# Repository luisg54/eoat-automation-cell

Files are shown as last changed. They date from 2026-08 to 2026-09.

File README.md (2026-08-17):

# EOAT Automation Cell

A small-scale automated pick station combining a custom-designed end-of-arm tool (EOAT), a
motion system, and PLC-based control logic — built to apply industry locating and fixturing
principles (NAAMS-inspired) and to integrate PLC sequencing with a separate motion
controller, mirroring how PLC-to-robot I/O handshakes work in real automation cells.

## Status

Concept and CAD phase. Started June 2026, primary solo project for Fall 2026.

Nothing is built yet. Some hardware is in hand — see [`electrical/bom.md`](electrical/bom.md).

## Repo structure

| Path | Contents |
|---|---|
| `cad/` | CAD models and renders for the gripper/EOAT and gantry |
| `firmware/` | Arduino motion control code |
| `plc/` | Allen-Bradley Micro820 ladder logic (CCW project files) |
| `electrical/` | Wiring diagrams and bill of materials |
| `docs/` | Requirements, test plan, build log, photos, demo videos |

Planning documents: [`docs/requirements.md`](docs/requirements.md) ·
[`docs/test-plan.md`](docs/test-plan.md) ·
[`docs/cycle-animation.html`](docs/cycle-animation.html) ·
[`docs/concept-sketches.html`](docs/concept-sketches.html) ·
[`HANDOFF.md`](HANDOFF.md)

## Project goals

- Design a gripper/locating fixture around a deliberate real-world constraint — geometry
  clearance and tolerance stack-up
- Validate the CAD design against a built, 3D-printed prototype
- Build a small motion system for pick sequences
- Integrate a Micro820 PLC for sensor logic, safety interlocks, and sequencing, handshaking
  with the motion controller

## Success criteria

The single statement that decides whether this project worked:

> The system shall autonomously detect, pick, transfer, and place a part for 50 consecutive
> cycles with at least 98% successful completion, documented fault handling, and measured
> positional repeatability.

Full requirement set in [`docs/requirements.md`](docs/requirements.md).

## Phases

Each phase is independently demonstrable. No phase starts before the previous one has
measured results.

| Phase | Goal | Demonstrable output | Status |
|---|---|---|---|
| 1 — Mechanical proof | One pick object, defined pickup and destination poses, one gripper/locating tool, one gantry X axis + short EOAT Z stroke, repeatable hard stops | Manual cycle with basic repeatability data | Not started |
| 2 — Motion and sensing | Motion controller, home switch, part-present sensor, end-position confirmation | Repeatable automatic pick-and-place cycle | Not started |
| 3 — PLC supervisory control | PLC owns cycle start, permissives, state sequence, sensor validation, faults, reset, and the handshake; motion controller owns low-level movement | Fault injected, detected, reported, recovered | Not started |
| 4 — Validation | Measure repeatability, pick rate, cycle time, fault recovery, tolerance sensitivity, payload, gripper retention, sensor robustness | Completed test report | Not started |

## Scope

**In scope:** one pick object (**608ZZ bearing**), one pickup pose and one destination pose, one gripper or
locating tool, one gantry (X) axis plus a short EOAT Z servo (≥ 15 mm) to clear locators, repeatable hard stops, home/part-present/end-position
sensing, PLC supervisory control over a motion controller, and measured validation.

**Explicitly out of scope:** multiple part types, a part feeder, vision, and any industrial
communication architecture beyond a simple PLC-to-motion handshake.

The known failure mode for a project like this is fragmenting it into five — a custom EOAT
plus a custom gantry plus motion control plus a PLC system plus a comms architecture — and
finishing none. The smallest complete system comes first, then it extends.

## Results

Empty until measured. This section gets filled from `docs/test-plan.md`, not from
expectations.

| Metric | Target | Measured |
|---|---|---|
| Positional repeatability | TBD | |
| Successful pick rate | ≥ 98% over 50 cycles | |
| Cycle time | TBD | |
| Payload | TBD | |

## License

See [`LICENSE`](LICENSE).

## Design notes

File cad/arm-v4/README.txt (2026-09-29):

REVISION D — DEVELOPMENT, owned-servo update 2026-09-28 (first D build 2026-09-12)

User-authored revision C fillets/chamfers were inspected and preserved before work.
The original cad/arm-v3 directory has not been regenerated or overwritten.

Owned servo geometry (authoritative, measured natively into owned-servo-measurements.json):
parts/MG996R_servo.SLDPRT   shoulder and elbow (two owned MG996Rs)
parts/SERVO_SG90.SLDPRT     yaw (one of four owned SG90s; three are unused spares)
Neither file contains a horn, so the joints drive straight off the splines.
The nominal HW-003/HW-004/HW-005/HW-006 envelopes, ARM-112 cap and their fasteners are
suppressed in every configuration of the D assembly (kept, not deleted).

Structural parts:
ARM-201 Upper link: owned MG996R elbow window/M3 ears; PCD18 hub bolt circle.
ARM-202 Yaw platform: derived from user C ARM-002; upright removed.
ARM-203 Shoulder upright: owned MG996R window and M3 ear holes; four-bolt foot.
ARM-204 Straight modular forearm: PCD18 hub bolt circle.
ARM-205 Removable Pololu 3551 gripper fork.
ARM-206 Two spacers preventing inward clamping of the gripper's plastic ears.
ARM-207 Printed MG996R spline hub (x2): press socket on the 25T spline, M3 centre screw.
ARM-003 Yaw collar: press socket on the SG90 spline; floating crossbolt hole.
ARM-004 Yaw cassette: SG90 ear holes on the measured 27.8 mm pitch.
FIT-003 / FIT-004: spline press-fit coupons. Print these, and FIT-001, first.

Scripts for this update: measure_owned_servos.py, owned_servo_design.py,
build_owned_servo_parts.py, update_owned_servo_assembly.py,
suppress_superseded_components.py; verification: check_motion.py,
check_transfer_path.py, save_pose_configurations.py, verify_saved_assembly.py.
One SolidWorks COM script at a time; restart SolidWorks if its working set nears 2 GB.

The supplier STEP and dimension drawing are preserved in source-reference.
HW-202 and HW-203 are purchased gripper reference geometry, not printed parts.
The gripper is a $29.95 candidate; supplier backorders were shown on 2026-09-12.

Use only fabrication-trial/manifest.json and its files for printing. Uncurated STL/STEP
files under parts are development exports, not a printing release. Do not print the parts
folder or fabrication-trial/superseded-2026-09-28.

development-debug/before-owned-servo-geometry-20260928-180253 holds the pre-update D.
development-debug/USER-C_20260912_original_references.SLDASM is a backup of C and
intentionally still references original C paths. It is not revision D.

Still required: servo spline press fits (FIT-003/FIT-004), bearing/dowel fits, calipering
the owned servos, tool access, cable routing, friction, temperature/current and repeated
cycles. More serviceable CAD does not establish production readiness without those tests.

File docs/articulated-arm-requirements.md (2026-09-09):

# Articulated arm prototype — active CAD requirements

On 2026-09-07 Luis explicitly selected an articulated robot arm and authorized identifying additional hardware. The older single-X-slide plus EOAT-Z scheme in `requirements.md` is historical context, superseded for this CAD task.

1. Create base yaw, shoulder pitch, elbow pitch and a working gripper in SolidWorks Design 2026. Use purchased SG90s where suitable. Preserve a provisional 20 g payload target from prior requirements; it remains unverified.
2. Design serviceable joints with explicit radial support, axial retention, fasteners, horn connections, mounting adjustment and cable paths. Incorporate the purchased 608ZZ and 6.35 × 25.4 mm dowel dimensions correctly. Never treat incompatible diameters as a fit.
3. Check first-principles torque, mass, grip, motion and stability. Separate assumptions, source ratings, CAD measurements and physical results.
4. Produce named editable native parts and a native assembly with appropriate joint constraints, plus clearly labeled fabrication exports. Mesh-only models and fixed arrangements without functioning joints do not satisfy this task.
5. Verify solids, saved/reopened files, assembly references, travel, hardware access, working pickup poses and swept interference. Current 60/65 mm link sizing remains a candidate until verified with actual component mass and geometry.
6. Provide materials, printing, assembly, additional hardware and test guidance. Exact fastener stacks must be checked in CAD. No purchasing is authorized by this task.
7. Preserve the previous prototype, work in a separate revision folder and operate conservatively within 16 GB RAM. Close saved task-owned documents and avoid unnecessary detailed geometry.

Native CAD is in development. No physical performance result or print-ready release has been recorded.

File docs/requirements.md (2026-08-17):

# EOAT / Automation Cell — Requirements

**Written:** not yet finalized — draft seeded 2026-08-11
**Last revised:** 2026-08-13

Fill these in with real numbers before opening CAD. Targets marked TBD should be set from
realistic hardware performance, not from ambition. It is better to set a target you can hit
and then tighten it than to miss a number you invented.

## Success criteria

The single statement that decides whether this project worked:

> The system shall autonomously detect, pick, transfer, and place a part for 50 consecutive
> cycles with at least 98% successful completion, documented fault handling, and measured
> positional repeatability.

## Pick object (locked 2026-08-12)

| | |
|---|---|
| **Part** | 608ZZ skate bearing |
| **Why this part** | Rigid, identical, cheap, ferrous (inductive prox), light enough for the SG90, and it has an ID that can take a locating pin — the same class of constraint problem as industrial hole locating |
| **Nominal geometry** | 22 mm OD / 8 mm ID / 7 mm width |
| **Nominal mass** | ~12 g (confirm on a scale before setting final P-04) |
| **Qty to buy** | 5 (spares for drop and offset tests) |

A round bearing has **no clocking datum**. Full 3-2-1 (hole + slot + plane) is out of scope for this object. That is accepted. What this object *is* set up to teach:

- **Hole locating** — pickup nest constrains XY with an ID pin and Z with a rest face
- **Clearance vs constraint** — gripper jaws must approach and retract without hitting the pin or rest pads
- **Constraint transfer** — pickup locates on the ID pin; destination locates on a different scheme (OD pocket or second pin), so the part leaves one datum set and enters another
- **Tolerance sensitivity (P-06)** — offset the part on the pin until pick fails; that number is the interview result
- **Retention without relying on the gripper to locate** — jaws hold for transfer only

If the design becomes two 3D-printed fingers pinching the rim and dropping it in a dish, this object teaches almost nothing. The nest and the clearance problem are the project. The bearing is just the payload.

## Motion scheme (locked 2026-08-13) — option A

A vertical ID pin only works if the tool can come down onto it and lift off it. One gantry
motor that only slides left–right cannot do that.

| | Role | Hardware |
|---|---|---|
| **X** | Transfer between pickup and destination | One powered gantry / linear axis (stepper). Phase 1–2 drives **only this axis** |
| **Z** | Short lift to clear locators (~15–20 mm) | Second SG90 (or equivalent) **on the EOAT**, not a gantry Z |
| **Grip** | Open / close only — does not locate | SG90 already in hand |

Cycle: lower onto pin → close grip → lift clear → X transfer → lower into destination nest → open → lift → return.

Concept sketches (cross-section): [`concept-sketches.html`](concept-sketches.html).

Design intent (confirm when hardware is in hand):

- Pin standout above the rest face: **≤ 6 mm** (stays inside the 7 mm bearing width so jaws can close on the OD)
- Destination OD pocket depth: **~3–4 mm** (captures the part, still liftable)
- Z stroke: **≥ 15 mm** (clears pin + pocket + approach margin)

This is not a 2-axis or 3-axis gantry. A purchased V-slot kit may still have unused axes
mechanically present; they stay unpowered through Phase 2.

## Functional requirements

| ID | Requirement | Verification method | Status |
|---|---|---|---|
| F-01 | The system shall detect the presence of a part at the pickup pose before initiating a cycle | Test | Not verified |
| F-02 | The system shall pick a single part from a fixtured pickup pose | Test | Not verified |
| F-03 | The system shall transfer the part along one gantry (X) axis to a defined destination pose | Test | Not verified |
| F-04 | The system shall confirm part placement before returning to home | Test | Not verified |
| F-05 | The system shall home on start and confirm the home position via switch | Test | Not verified |
| F-06 | The PLC shall own cycle start, permissives, state sequencing, fault detection, and reset | Demonstration | Not verified |
| F-07 | The motion controller shall own low-level movement and shall act only on a PLC permissive | Demonstration | Not verified |
| F-08 | The pickup fixture shall fully locate the bearing before gripper close: Z rest face + ID pin. The gripper shall not be the locator | Inspection + test | Not verified |
| F-09 | Gripper jaws shall clear the pickup locators on approach and retract with no contact | Inspection | Not verified |
| F-10 | The destination fixture shall locate the bearing with a **different** datum scheme than pickup (OD pocket or second pin, not a copy of pickup) | Inspection | Not verified |
| F-11 | The EOAT shall provide a Z stroke ≥ 15 mm to clear pickup and destination locators before any X motion. Z is a tool servo, not a gantry axis | Test | Not verified |

## Performance requirements

| ID | Requirement | Target | Measured | Status |
|---|---|---|---|---|
| P-01 | Positional repeatability at the destination pose | ± TBD mm | | Not verified |
| P-02 | Successful completion rate | ≥ 98% over 50 consecutive cycles | | Not verified |
| P-03 | Cycle time | ≤ TBD s | | Not verified |
| P-04 | Payload | ≥ 20 g | | Not verified |
| P-05 | Gripper retention through full transfer | 0 drops in 50 cycles | | Not verified |
| P-06 | Tolerance sensitivity — part position offset the system still handles | ± TBD mm | | Not verified |

## Interface and environment

| ID | Requirement |
|---|---|
| I-01 | Operates from a single bench supply at TBD V, ≤ TBD A |
| I-02 | Fits within a TBD × TBD × TBD mm bench envelope |
| I-03 | Operates on a standard desk or bench surface without anchoring to the building |
| I-04 | Assembles and disassembles with hand tools only |

## Safety and fault handling

| ID | Requirement |
|---|---|
| S-01 | The system shall reach a safe, de-energized state on loss of power, without dropping a held part onto a hand path |
| S-02 | The system shall detect a missing part at pickup, report the fault, and require an explicit reset |
| S-03 | The system shall detect a failed placement confirmation, report the fault, and require an explicit reset |
| S-04 | The system shall detect a homing failure and refuse to run a cycle |
| S-05 | No motion shall be commanded without a PLC permissive |

Fault handling is a first-class requirement here, not an afterthought. A cell that only works
when nothing goes wrong does not demonstrate anything an automation employer cares about.

## Constraints

- **Budget:** **$250 for the cell** (gantry / one powered axis, drivers, PSU, sensors,
  printed EOAT/nests, pick object, extra servo if needed). **PLC is separate:** borrow from
  WashU first; if buying a Micro820, expect ~$200–400 on top. Do not fold the PLC into the
  $250 or replace it with “Arduino does both.” If a decent linear kit alone blows past ~$150,
  raise the cell budget rather than cheap out on the axis you will use all semester.
- **Timeline:** Fall 2026 semester, alongside one selective team or research activity
- **Tools available:** TBD — confirm machine shop, 3D printing, and PLC hardware access
- **Skills to be learned:** locating / constraint (ID pin + rest, clearance vs locator
  geometry), datum transfer between fixtures, tolerance sensitivity, PLC ladder logic,
  state machines, PLC-to-motion handshakes, safety logic fundamentals, fault recovery,
  sensor selection, electrical schematics

### Hardware already in hand

Prototyping against these costs nothing and can start immediately.

| Item | Use |
|---|---|
| ELEGOO Mega R3 | Motion controller for Phases 1–2 |
| SG90 servo | Gripper open/close — verify it meets P-04 payload and P-05 retention |
| Breadboard and jumper set | Sensor and I/O bring-up |

### Hardware identified, not ordered

Allen-Bradley Micro820 `2080-LC20-20QWB`, NEMA17 steppers, TB6600 drivers, 24 V supply,
inductive proximity sensors, limit switches, V-slot gantry kit. Full list and status in
`../electrical/bom.md`.

**Axis decision (locked 2026-08-13):** Phase 1–2 powers **one gantry axis (X)** plus a tool
Z servo (F-11). Do not buy or wire three TB6600s for Phase 1. A 3-axis kit is allowed only
if it is cheaper as a kit; unused axes stay unpowered. See `../HANDOFF.md`.

## Revision log

| Date | Requirement | Change | Why |
|---|---|---|---|
| 2026-08-11 | all | Initial draft seeded from the Fall 2026 plan | Project scoping |
| 2026-08-12 | pick object, F-08–F-10, P-04 | Locked 608ZZ; locating/clearance rules; payload ≥ 20 g | Object choice + keep the EOAT from becoming a pinch gripper |
| 2026-08-13 | budget | Cell $250; PLC separate, borrow-first | Avoid Arduino-as-PLC and under-buying the axis |
| 2026-08-13 | motion, F-03, F-11 | Option A: one gantry X + EOAT Z servo ≥ 15 mm | Vertical ID pin is otherwise kinematically impossible |

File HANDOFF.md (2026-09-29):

# EOAT Automation Cell — Handoff

## Active revision D — owned-servo update, 2026-09-28

**Model:** `cad/arm-v4/ARM-D_Modular_parallel_gripper_DEVELOPMENT.SLDASM`. Development only, not a print release.

- 191 active components, 44 fastener stacks, 24 printed pieces across 15 types.
- The 75 nominal-servo components (HW-003/004/005/006, ARM-112 and their fasteners) are suppressed in all 8 configurations. Their 77 mates are suppressed and renamed `*_superseded_nominal_servo`. Nothing was deleted.
- Pre-edit backup: `cad/arm-v4/development-debug/before-owned-servo-geometry-20260928-180253/` (assembly, changed parts, reports, docs, SHA-256 manifest).
- Revision C and `cad/arm-v3` are untouched; all 38 hashes re-checked.

**Measured on the two servo files.** Native B-rep via `measure_owned_servos.py`, written to `owned-servo-measurements.json`. Datum: ear underside on the output axis.

- **`MG996R_servo.SLDPRT`** — native part, 2 bodies (case; spline with modeled M3 thread). No material, **no horn, no cable**.
  - Ears: Ø4.0 open-slot holes at −14.15 / +34.15 × ±5.00 mm (a 48.30 × 10.00 pattern), 19 mm wide. Thickness 2.40 mm at the output end but 1.754 mm at the far end (asymmetric in the file).
  - Case: 40.0 mm at the ears, 40.7 at the bottom (1° draft), × 20.0; 27.99 below the ears.
  - Heights above the ear underside: case 7.5, cover 10.0, raised block 11.0, Ø13.2 boss 11.5, Ø10.8 output ring 12.0, spline top 15.5.
  - Spline: 25 V-teeth, tip Ø5.997, root ≈Ø5.42, 3.5 mm exposed. M3 centre thread 8.19 mm deep.
- **`SERVO_SG90.SLDPRT`** — STEP import, 5 bodies (case, spline, 3 cable stubs). No material, **no horn, no tooth form, no thread**.
  - Ears: 2.4 mm thick, Ø2.5 open-slot holes at −8.4 / +19.4 mm (27.8 pitch). Hole centres are only 2.4 mm from the case walls.
  - Case: 12.0 × 23.0.
  - Gear cover (Ø12 plus a Ø5 lobe at +6.0): top 11.4 above the ear underside, 9.0 above the ear top (D assumed 8.8).
  - Spline: plain Ø5.0 with 40 shallow grooves, 3.0 mm exposed, top 14.4 above the ear underside. The old 13.2 mm horn-front assumption no longer applies.
  - Centre hole: plain Ø1.0. Cables exit the output end 12.7 mm below the ears.

**Functional changes, and why:**

1. **MG996R mounts (ARM-203, ARM-201).**
   - The window is now 41.7 × 21.0 mm: the file's widest case section plus 0.5 mm per side. The old window left 0.15 mm.
   - Ø3.4 holes sit on the measured pattern; the old holes were 1.15 mm off.
   - M3 × 14 with two washers and a nyloc replaces M2.5, because the Ø4 slotted ears need M3. M2.5 hardware is gone from the BOM.
2. **ARM-207 printed spline hub (×2, new)** replaces the unowned OD20/PCD14 metal-horn stack.
   - Ø5.80 press socket over 3.0 mm of the 25-tooth spline; underside 0.5 mm above the output ring.
   - 1.0 mm floor seated on the spline top, clamped by an M3 × 8 low-head centre screw with 7.0 mm engaged.
   - Four M3 × 12 on an 18 mm bolt circle into captured M3 nuts.
   - The hub is sized so the link rear faces stay 16.5 mm above the ears, so world Z is unchanged. Dowels, sleeves, cheeks, 32 mm standoffs and M3 × 50 stacks are all unchanged.
   - The centre-screw head sits inside the link-side sleeve, 1.0 mm below the dowel.
   - A separate hub keeps each link's print face flat and makes a stripped socket a small reprint.
3. **ARM-201 / ARM-204:** the PCD14 metal-horn holes are suppressed; PCD18 holes and washer seats are added.
4. **ARM-004:** SG90 ear holes move to −8.4 / +19.4 mm; each was 0.6 mm off. M2 × 10 with no washers, because a Ø5 washer would overlap the case wall by 0.1 mm. Nut flats face the case.
5. **ARM-003:**
   - The horn pocket is suppressed and replaced by a Ø12 boss with a Ø4.85 × 2.5 mm press socket, 0.5 mm above the gear cover.
   - A 1.2 mm floor seats on the spline top, with the SG90 horn screw; its head clears the spindle end by 0.4 mm.
   - The crossbolt hole is opened to Ø2.8 (±0.4 mm axial float). The servo now locates the collar and the platform weight stays on the 608s. The old round hole over-constrained the yaw stack.
6. **ARM-112 cap, its four low-profile M2 × 10 (Ø4 × 1.1) screws, washers, nuts, and FIT-002 are superseded.** There is no horn left to capture, and it removes a hard-to-source screw.
7. **`03_Pickup_trial` moved from −15/−80 to −15/−75.** The forearm is now vertical, so the jaws are coaxial with the pin. The jaw tips sit 16.5 mm above the bench at z ≈ 75.
8. **Pin-safe lift defined:** a Cartesian vertical lift for the first 10 mm (IK at the 90 mm grip point), during which the forearm rotates 1.14°. This replaces the joint-interpolated lift check.
9. **FIT-003 (Ø5.70–6.00) and FIT-004 (Ø4.65–4.95) coupons** will select the real press-fit bores.
10. **The three spare SG90s stay unused.** A wrist-pitch SG90 (about 17 g at about 150 mm) would take the governing shoulder margin from 1.14 to about 1.0, and the vertical lift doesn't need a wrist. Keep them as yaw spares and fit-test units.

**Verified in SolidWorks on the reopened assembly:**

- All 191 active references resolve inside `arm-v4` (38 unique parts).
- Zero mate errors and zero part feature errors (the servo files are allowed to be multibody).
- The 6 saved pose configurations match the kinematic model to ≤1.1×10⁻¹⁵, and the free-motion limits are valid.
- Interference in the 6 saved configurations, 11 review poses and 19 transfer/lift samples: **0 unexpected overlaps**.
  - Every state shows the same 93 designed engagements, reported separately: hub and collar press fits on the modeled splines, and centre screws in the modeled M3 thread and the SG90's Ø1.0 hole.
  - 0 mm closure keeps its 2 known supplier-model overlaps.
- All new sketches are fully defined and the unchanged-solid checks pass.
- Loads (solid density, 20 g payload): shoulder 0.243 N·m, margin 1.14, still governing; elbow 0.077 N·m, margin 3.58; total 639.3 g.
- Curated exports are refreshed for the 8 changed or new parts. The ARM-112 and FIT-002 exports moved to `fabrication-trial/superseded-2026-09-28`.
- Everything is saved and all CAD documents are closed; SolidWorks is left running with no documents.
- Resources: the SolidWorks session I started from already held about 3 GB of private memory. Its working set jumped to 3.47 GB after two small part builds, so I stopped, confirmed nothing was open or unsaved, and restarted it. After that, restarts between heavy runs kept the working set under 2 GB (peak 1.92 GB), well below the earlier 6.6 GB failure.
- `cad/sw_probe.py` now uses the installed pywin32 with late binding, because the `%TEMP%` bridge is gone.

**Still unproven on hardware:**

- The owned servos have not been calipered. The files were trusted as instructed, including the thin 1.754 mm far ear.
- Spline press fits and hub/collar torque and creep: run FIT-003 and FIT-004 first.
- Whether the original MG996R centre screw fits, or the M3 × 8 low head is needed. Whether the SG90 horn screw bites (the file shows only a Ø1.0 hole).
- The 0.5 mm running gaps under the hubs and collar at printed tolerance.
- Bearing and dowel fits (FIT-001) and crossbolt alignment.
- Cable routing across yaw and screwdriver access.
- Shoulder torque, current and temperature; the 1.14 margin is an estimate.
- Grip retention, repeatability, the 50-cycle test, and the pickup fixture itself.

## Previous D checkpoint - 2026-09-12 (superseded by the owned-servo update above)

**Latest saved model: `cad/arm-v4/ARM-D_Modular_parallel_gripper_DEVELOPMENT.SLDASM`.** 198 components, 45 fastener stacks. Verification in progress; no print or production release. Latest motion report: home: 5 overlaps.

User asked to improve functional geometry beyond fillets, including ARM-002/102/103. He owns TWO MG996Rs and permits sensible COTS. His saved C edits were inspected and preserved (38 unique parts, no feature errors; hashes in `user-revision-inspection.json`). Do not regenerate C. D derives ARM-201/202/203 from his native histories and copies unchanged parts from saved C.

New parts: ARM-201 upper link for both MG996Rs, ARM-202 separate yaw platform, ARM-203 bolt-on upright, ARM-204 straight modular forearm, ARM-205 removable parallel-gripper fork, ARM-206 crush spacers (two). Both pitch joints use 20.5 mm horn spacing, 32 mm standoffs, OD20/PCD14 metal horns. One SG90 remains for yaw. Tool candidate is Pololu 3551, 32 mm stroke, supplier 30 g including FS90-FB servo, $29.95; supplier showed backorders. Official STEP/PDF saved and drawing visually inspected. HW-202/HW-203 are supplier body/jaws. No purchase occurred. Fork uses the actual two 4.2 mm axes, M4x35, 0.5 mm small-series washers, nylocs and 13 mm crush spacers inside 13.4 mm ear gaps. Four M3x16 attach the adapter; four M3x20 attach the upright.

Resource fix: visible part windows grew SW to ~6.6 GB and a fastener OpenDoc returned null. Saved 158-component partial insertion under `development-debug/D_partial_insertion.SLDASM`; resumed without rebuilding with `--resume-partial`, DocumentVisible(False,1), CommandInProgress=True. Complete model saved; SW was ~0.86 GB. Keep component windows hidden during assembly insertion; do not run concurrent COM scripts. Initial jaw alignment QA caught flipped imported planes; corrected with closest alignment and a flipped right-side opening distance. Superseded mates are suppressed, not deleted. Full builder now includes these settings and a pre-mate save checkpoint.

Next: finish transform/collision checks including reduced shoulder clearance with larger elbow case, calculate D loads/BOM, constrain new sketches, verify saved configurations/references, update guide/BOM and curated exports. Current documents below still describe C until explicitly revised. Physical horn fit, bearing/dowel trials, cables/driver access, grip force/current and repeatability/cycle evidence remain required. User latest instruction: continue and verify carefully; usage reset, laptop 16 GB. No new subagents authorized.

## Active CAD session — 2026-09-08

**Latest checkpoint: Arm 3 / Revision C is built and verified in CAD.** Open `cad/arm-v3/ARM-C_Articulated_prototype_DEVELOPMENT.SLDASM`. It has 190 components, 185 rigid attachments, four articulated joints, 43 fastener stacks, and 24 printed instances across 16 active part types. Those printed types contain 115 fully constrained sketches with unchanged-solid checks. `saved-assembly-verification.json` confirms clean reopen, all 190 native references, six saved pose transforms, zero active mate errors and native free-motion limits. Nine review poses and twelve lift/yaw samples have zero native solid overlaps. These are discrete samples; no full swept-clearance or physical performance claim is made.

C corrects the SG90 raised gearbox-cover envelope and compact horn hub projection, lowers the removable yaw-servo shelf, increases elbow axial spacing to 19.6 mm and its printed standoffs to 28.6 mm, and lengthens the moving finger while retaining pad contact height. Each compact stock horn is captured in a shaped pocket with an ARM-112 cap and four M2 × 10 low-profile screws (head maximum D4 × H1.1). The C shoulder uses an OD20 / PCD14 M3-tapped metal-horn reference and raised washer seats. No tiny stock horn pilots need drilling. C native views in `review-images` were visually inspected.

**Physical fit hold:** the 13.2 mm seated SG90 horn-front height above its ear top is an assumption; Luis has been asked for this measurement. The minimum modeled screw/gear-cover axial gap is 0.2 mm, so the real cap must clear through travel before release. Three FIT-002 pocket clearances and a cap are the next small print trial, alongside FIT-001 bearing/dowel checks. Confirm actual MG996R/horn dimensions, assembly insertion, driver access and cable paths. Final fastener ordering depends on these checks and a quote for the twelve low-profile M2 screws. User prefers simple COTS envelopes and can import purchased models; avoid detailing internals.

C load estimate: 526.0 g modeled mass at solid-density assumptions; with 20 g payload, elbow design torque 0.04273 N m versus assumed 0.05884 budget (margin 1.38), shoulder 0.13363 versus 0.27655 (margin 2.07). These are sizing estimates, not measured ratings. `docs/arm-bom.md` now matches C native quantities; `docs/arm-print-and-assembly-guide.md` follows the revised physical stack and staged purchase/print/test plan. Budget remains an allowance of about $180–285, pending current quotes. No purchases occurred. Curated C fabrication exports are complete: `fabrication-trial/manifest.json` lists 20 individual part/coupon types with zero mesh failures and native-volume checks. Print the four coupon types and one ARM-112 cap first. All saved task CAD documents were closed after exports to release memory; SolidWorks itself remains open. Preserve B as the prior checkpoint and the C development backups. Goal remains incomplete pending fabrication/access checks and physical fit/test evidence.

### Preserved Arm 2 checkpoint and prior-session context

Luis explicitly switched the CAD task to an **articulated robot arm** and authorized identifying additional hardware. See `docs/articulated-arm-requirements.md`; the older X-slide architecture below is historical context.

Current native SolidWorks 2026 work is in `cad/arm-v2`; revision A and the original demonstration are preserved. B has 199 components, 21 printed instances across 15 part types, 41 explicit fastener stacks, a removable yaw servo cassette, bearing retainers, positive yaw crossbolt and captured TPU pads. Shoulder ears use M2.5 hardware. The moving-pad servo-ear relief is now built. The fit coupon is built in B. `sketch-constraint-report.json` records 98 fully constrained sketches across 16 files (15 arm types plus coupon), with unchanged-solid checks.

**Native motion now works with dimension-driven mates.** Rebuilding the 194 rigid attachments finished. `refresh_joint_references.py` replaced stale joint references after part regeneration, fixing shoulder pivot translation. Direct `SetTransformAndSolve2` still failed to propagate the full rigid groups reliably; use the four native angle command dimensions instead. `check_motion.py` now does that and independently compares all 199 component transforms against kinematics. Nine revised poses passed with zero solid overlaps (`motion-inspection.json`). The previous -40/-50 shoulder/elbow pickup hit the yaw platform; revised pickup is -30/-60. Twelve samples of lift/yaw transfer also passed (`transfer-path-inspection.json`). These are discrete samples, not a swept proof; cables, tool access, payload and external fixtures are excluded.

Six native pose configurations are saved and their independent dimensions were read back (`pose-configurations.json`). `07_Free_motion_CHECK_COLLISIONS` suppresses command mates and uses four native angle-limit mates; values and zero feature errors verified in `native-motion-limits.json`. Provisional physical-angle bounds: yaw -60..60, shoulder -30..80, elbow -100..-5, grip 0..25. Arbitrary combinations are not certified collision-free. Native config switches invalidate cached component COM objects; re-fetch GetComponents after switching. `SaveConfiguration2` is not used: ShowConfiguration2 can return false when already active, so inspect ActiveConfiguration.Name.

**Fabrication hold at horn interfaces.** The modeled MG horn is a nominal 26 mm plate / 20 mm bolt circle. A sourced common 25T metal disc is 20 mm OD / 14 mm bolt circle / 4.5 mm total thickness / 2 mm plate, four M3 tapped holes (drawing linked in guide). It cannot be substituted directly. Select a real horn, update the upper-link pattern, washer relief, screw engagement and axial stack, then refresh affected mates and recheck. Existing MG model plate front is world Z23; the source metal disc with hub beginning Z16 would put its front at20.5, requiring a stack change. SG90 modeled hole radii8 and M2 through fasteners also require matching to owned horns; supplier drawing shows r8.3 and ~1 mm pilots. Do not release the horn-connected parts or order their fasteners yet. User was asked asynchronously whether calipers/PETG/TPU are available; no reply yet.

The current shoulder proposal is one additional MG996R positional servo; three purchased SG90s handle yaw, elbow and grip. The 3:1 SG90 shoulder candidate was rejected because of restricted travel and small load margin. Upper centers are60 mm; nominal forearm contact65 mm, with a better-centered circular payload location at forearm(69,1,3) mm. `calculate_cad_loads.py` now uses native volumes, conservative printed density and motion-group lever bounds, including jaw rotation. With20 g payload: design elbow0.04088 N m versus0.05884 budget (margin1.44); shoulder0.12858 versus0.27655 (margin2.15). Total modeled mass518.4 g at solid-density assumptions, not a weighed result. Ideal22 mm bearing contact occurs at grip7.83deg; assuming mu0.3 and weight factor2, estimated0.849 N/contact and0.01683 N m grip torque. The 10deg CAD transfer pose is a clearance demonstration, not a holding command. All physical fits, actual servo ratings, pad friction and duty-cycle tests remain pending.

**Earlier C preparation (superseded by the latest checkpoint above):** revised horn-interface parts and FIT-002 coupons were initially generated without a complete assembly. The resumed session subsequently built and verified that C assembly. Arm 2 is preserved for comparison.

`docs/arm-print-and-assembly-guide.md` includes the full gripper-to-bench walkthrough, materials, per-part orientation, configuration controls, calculations and horn fabrication hold. `docs/arm-bom.md` has native-verified development quantities and planning allowances. User explicitly allows useful function improvements beyond the historical$250 target. A compatible shoulder horn adds an estimated$5–10 to the earlier$175.12–275.12 total; no purchase occurred. Only the supply has a checked fixed quote. Native colors and component references are saved; `review-images` contains actual SolidWorks BMP views, visually inspected. SW working set stayed around1.3–1.4 GB. Curated fine/mm exports are being generated by `export_fabrication_trials.py` into `fabrication-trial/fit-coupon` and `candidate-parts`, with mesh/native-volume checks and a manifest. Raw `parts` still preserves mixed assembly STLs; use only curated files for trial fabrication. Remaining: finish export and saved/reopened QA; resolve actual horn interfaces, insertion/tool/cable access and continuous travel; physically fit/test. Goal is not complete and no full print-ready release has occurred.

SolidWorks initially failed to finish startup; Luis opened it manually and authorized control. The COM connection now works (revision 34.3.2). Temporary failed sketches were preserved under `cad/arm-v1/development-debug` before closing them. Scripts use the bundled Python 3.12 plus a temporary pywin32 bridge and require the desktop COM session.

---

**Historical handoff last updated:** 2026-09-03
**Status:** Phase 1 parts **ordered** (608ZZ 20-pack + 1/4" × 1" dowels + SG90 4-pack, ~$20). ETA ~Sat 2026-09-05. Nothing built yet. WashU makerspace / 3D print access **confirmed**. Cardboard mock starts after delivery.
**School start:** 2026-08-24. Pre-school window is 2026-08-12 → 2026-08-23.

## Current state

Repo scaffolded in June 2026 with the `cad` / `firmware` / `plc` / `electrical` / `docs`
layout. No CAD models committed, no firmware, no ladder logic, no wiring diagrams.

A bill of materials exists in `electrical/bom.md` with real part selections. Three items are
already owned: an ELEGOO Mega R3, an SG90 servo for gripper actuation, and a breadboard and
jumper set. Phase 1 order placed 2026-09-03 (ETA ~Sat 9/5): 608ZZ 20-pack, 1/4" × 1" dowels,
SG90 4-pack. Gantry / Micro820 / drivers still not ordered — correctly deferred.

Scope, phases, and success criteria are in `README.md`. Testable requirements are in
`docs/requirements.md`. Pick object is locked: **608ZZ bearing**, located by an ID pin +
rest at pickup and a different datum scheme at destination (F-08–F-10). Motion is locked:
**one powered gantry X + EOAT Z servo ≥ 15 mm (F-11)**. Payload P-04 is ≥ 20 g. Remaining
TBDs wait on gantry selection and the SG90 mock.

## Scope tension — resolved for Phase 1–2 (2026-08-13)

**Option A locked:** one powered gantry axis (X) + a short Z servo on the EOAT (≥ 15 mm) to
clear the vertical ID pin. Z is not a gantry axis and does not justify buying/wiring three
TB6600s.

A 3-axis V-slot kit is still allowed if it is cheaper as a kit. Unused axes stay
mechanically present and **unpowered** through Phase 2. Do not treat kit-Z as the lift.

## Blockers

| Blocker | Impact | What would unblock it |
|---|---|---|
| ~~Machine shop / 3D printing access~~ | **Cleared 2026-09-03** — WashU makerspace + 3D print access confirmed | Fabricate after cardboard mock passes |
| Micro820 not ordered | Phase 3 cannot start | Check whether a lab unit can be borrowed before buying; confirm Connected Components Workbench access |
| Budget not set | Cannot order long-lead items | **Partial lock:** $250 cell; PLC separate. Raise cell budget if the linear kit is >~$150 |
| Axis count not decided | ~~Blocks the BOM order~~ | **Resolved:** one powered X + EOAT Z servo. Kit extras stay unpowered |
| Performance targets still TBD (P-01, P-03, P-06) | Requirements not fully testable | Set after SG90 mock + gantry choice. P-04 is locked at ≥ 20 g |

## Open questions

- Is the gripper SG90 adequate to retain a 608ZZ through transfer (P-05), including during
  the Z lift? Cheap to test 8/15–8/17. Order bearings + dowels + second SG90 first.
- Is a physical Micro820 worth buying, or is a simulated PLC acceptable for demonstrating
  state-machine and handshake logic? Physical hardware is a much stronger interview story.

## Next steps

### Session — 2026-09-03

- Phase 1 Amazon order placed (Luis, afternoon 2026-09-03). Cart: 608ZZ (20), 1/4" × 1" dowels (15), SG90 4-pack. ~$20. ETA ~Sat 2026-09-05.
- Luis has WashU makerspace / 3D print access (blocker cleared).
- Owned unchanged: ELEGOO Mega R3, one kit SG90 (gripper), breadboard/jumpers.
- **Next after delivery:** cardboard/foam mock (jaws + Z lift off pin, hand-slide X). Pass/fail retention + pin clearance. Household tape/glue. Mega USB power. Do not buy more until mock results.

### Active — from 2026-08-31

SpaceX call is done. Still in process until they email (~1 week from 8/28). **Do not wait on
that to start building.**

This week, split time:

1. **EOAT Phase 1** (primary build): **order placed**, waiting on ~Sat 9/5 delivery → cardboard
   mock (jaws + Z lift off pin, hand-slide X). Pass/fail on retention and pin clearance.
   Shop/print access already confirmed.
2. **Interview repair** (20 min/day, parallel): cantilever / shear / bolts-vs-pins drill per
   `Career/Interview-Prep/Mock-Sessions/2026-08-28-spacex-phone-debrief.md` — round 2 or
   the next company will ask the same chain.

Do **not** yet: gantry kit, Micro820, firmware, full-cell CAD.

### Was paused — through Fri 2026-08-28

### Stopped — 2026-08-13 ~01:08 (sleep)

Session done. Concept is locked and the 3D cycle is in `docs/cycle-animation.html`.

**When you wake up:** order 608ZZs + two 1/4" × 1" dowels + extra SG90 (~$15–30). Internship wrap still owns Thu–Fri — no build until Sat 8/15. Then cardboard mock: jaws + Z lift off the pin.

### Done — 2026-08-12 / early 2026-08-13

Pick object locked: **608ZZ**. Locating rules in `docs/requirements.md` (F-08–F-10). P-04 ≥ 20 g.

**Order soon:** 5–10× 608ZZ + two 1/4" × 1" steel dowel pins + one extra SG90 (Z). Listed in
`electrical/bom.md`. ~$15–30 total.

**Budget partial lock:** $250 for the cell. Micro820 is **not** in that number — borrow from
WashU first; buy only if they will not loan one (~$200–400 extra). Arduino is the motion
controller, not a substitute PLC.

**Kinematics locked — option A.** One gantry X + EOAT Z servo ≥ 15 mm. Pin standout ≤ 6 mm.
Destination pocket ~3–4 mm deep. Animated full stack: `docs/cycle-animation.html`.

### Pre-school window — 2026-08-13 → 2026-08-23

Internship wrap-up still competes through **Fri 8/14**. Do not start a build those two days.
From **Sat 8/15** this is the primary technical work.

| When | Do | Do not |
|---|---|---|
| 8/13–8/14 | Optional: sketch the cycle on paper (lower → grip → lift → X → lower → open). No CAD. | CAD the full cell, order the gantry, open firmware |
| 8/15–8/17 | Cardboard/foam mock: jaws + Z lift off a 1/4" dowel + Mega + both SG90s. Pass/fail on P-05 through a hand-moved X transfer. Photograph it. | Wait for 3D printing. A mock that fails is more useful than a pretty jaw you cannot print yet |
| 8/18–8/20 | Replace every TBD in `docs/requirements.md` with numbers from the mock + datasheets. Set a budget ceiling. Price a **one-axis** BOM (or kit-with-two-axes-unpowered). Flag anything >2 week lead time | Order three TB6600s "just in case." Do not buy the Micro820 until you know whether WashU will loan one |
| 8/21–8/23 | Email/check WashU shop + 3D print training + Micro820 / CCW access so day 1 of school is not spent hunting that. Create the project in Engineering OS. If Fusion/SW is available at home, CAD **jaws + nest only** around the locked object | Start Phase 2 motion code. Do not begin a second project |

Success for this window is **not** a running cell. It is: pick object locked, SG90
retention known, requirements no longer TBD, budget set, long-lead flagged, shop/PLC access
asked, one-axis Phase 1 ready to fabricate the week of 8/24.

### After school starts — 2026-08-24

Start Phase 1 fabrication (printed jaws/nest, hard stops, one linear axis). Do not begin
Phase 2 until Phase 1 has measured repeatability data.

## Risks

- **Scope creep**, and specifically the three-axis question above.
- **Long-lead parts stalling the semester.** Flag anything over two weeks and order early.
- **Stopping at CAD.** A modeled cell with no test data does not satisfy the point of this
  project. Phase 4 is not optional.
- **Competing commitments.** The plan is one serious solo project plus one selective team or
  research activity. More than that puts this one at risk.

## Resume prompt

> I'm continuing work on `eoat-automation-cell`. Read `HANDOFF.md`, `README.md`, and
> `docs/requirements.md` for context, plus `Projects/Rules.md` in the dashboard. I need help
> with <next task>.

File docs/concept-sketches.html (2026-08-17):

# EOAT cell — 3D concept

Open the animated full-stack cycle (Play / Pause / scrub). Stills below.

The pick object is a 608ZZ donut. Pickup locates it with a pin through the hole plus a rest. Destination locates it with a shallow cup on the outside. Jaws only hold. One gantry slides X. A short Z on the tool lifts off the pin before that slide.

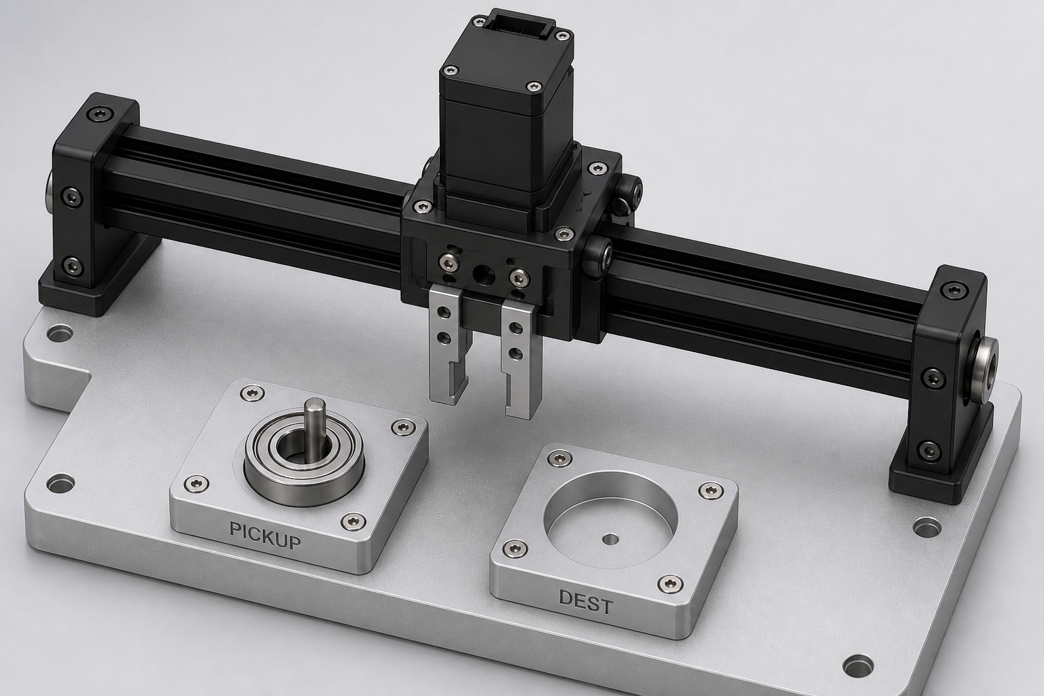
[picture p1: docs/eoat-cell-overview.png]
Isometric 3D of the bench cell: rail, EOAT, pin nest, pocket nest


Whole cell. Left nest = pin through the bearing. Right nest = OD pocket. Rail is the only gantry axis.

## Cycle

1. Located — donut on the rest, pin through the hole. Nest locates. No gripper yet.
2. Z down, jaws open — come straight down. Must miss the pin.
3. Close — grab the outside. Pin still locates.
4. Lift ≥ 15 mm — donut comes off the stick. Sideways is illegal until this is done.
5. X transfer — one gantry axis. Bearing in the air.
6. Set in pocket — lower into the OD cup. No pin.
7. Open, lift, home — part stays in the cup.

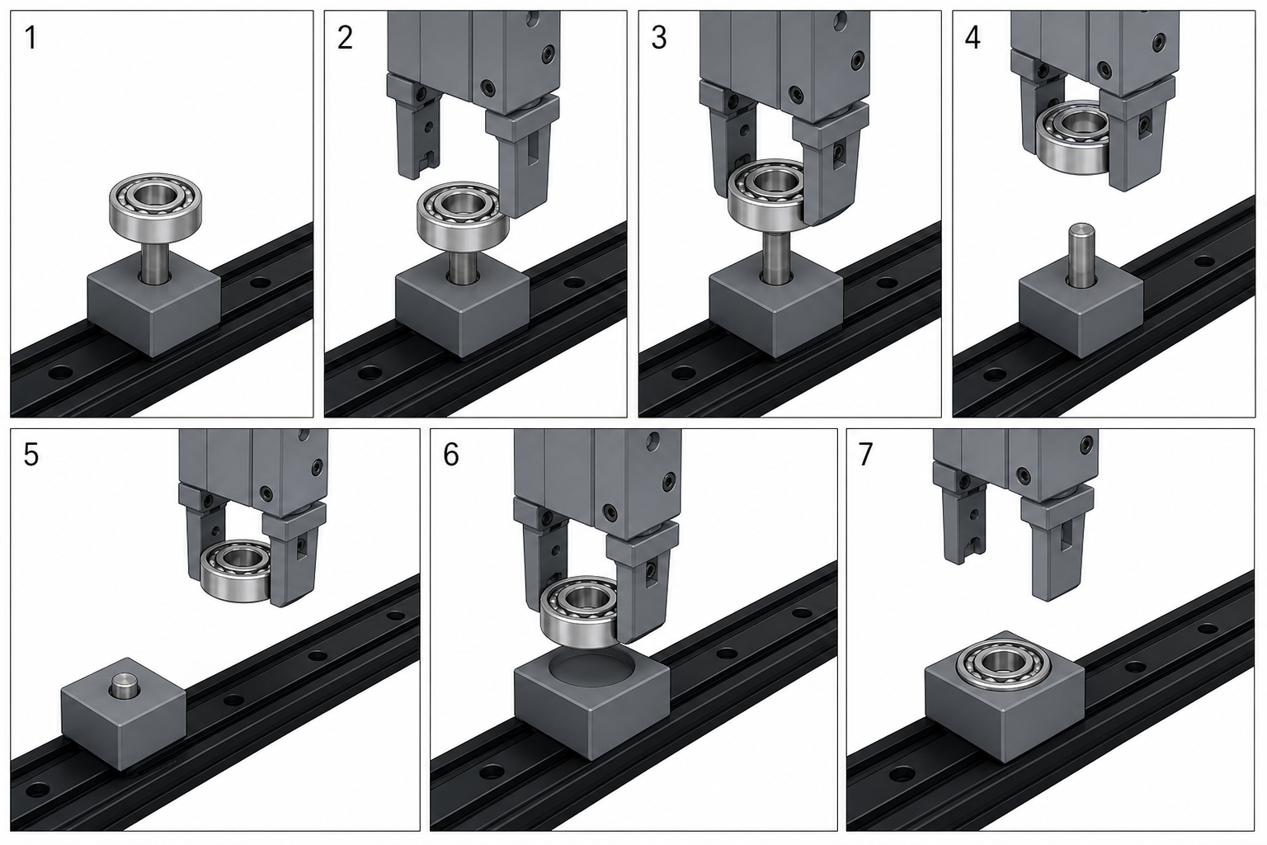
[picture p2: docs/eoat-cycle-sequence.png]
Seven-frame 3D cycle from pin pickup to pocket place


Same camera, seven frames. If a frame still has the pin in the hole, you cannot slide X yet.

## Why the nests are different

If destination were another pin, you would learn almost nothing new. Pickup = hole locating. Destination = outside locating. The part leaves one datum set and enters another.

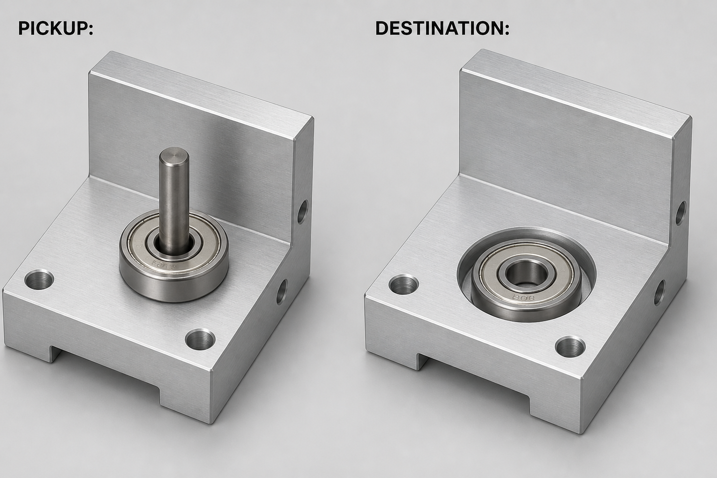
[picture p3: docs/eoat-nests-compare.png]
Close-up: ID pin nest versus OD pocket nest


Pickup: 1/4" pin, standout ≤ 6 mm inside the 7 mm bearing width. Destination: ~3–4 mm OD pocket.

Locked 2026-08-13. Motion option A. See requirements.md F-08 through F-11.

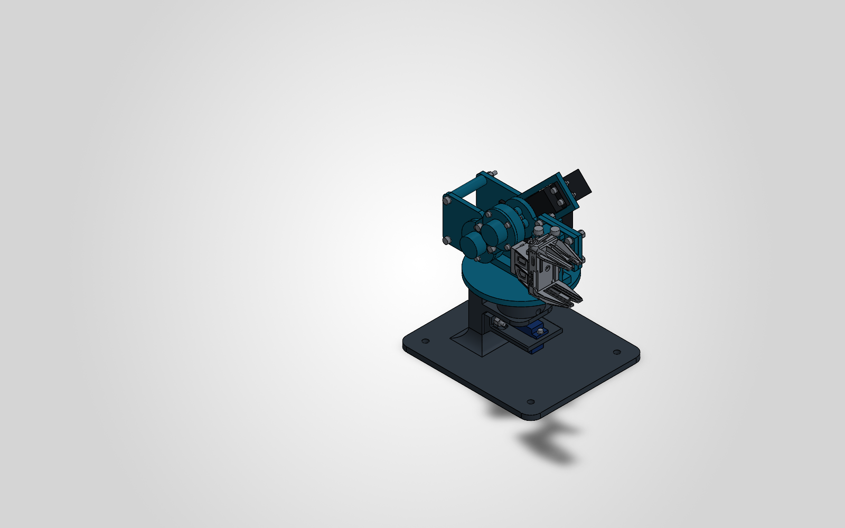
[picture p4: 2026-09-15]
cad/arm-v4/review-images/isometric.bmp

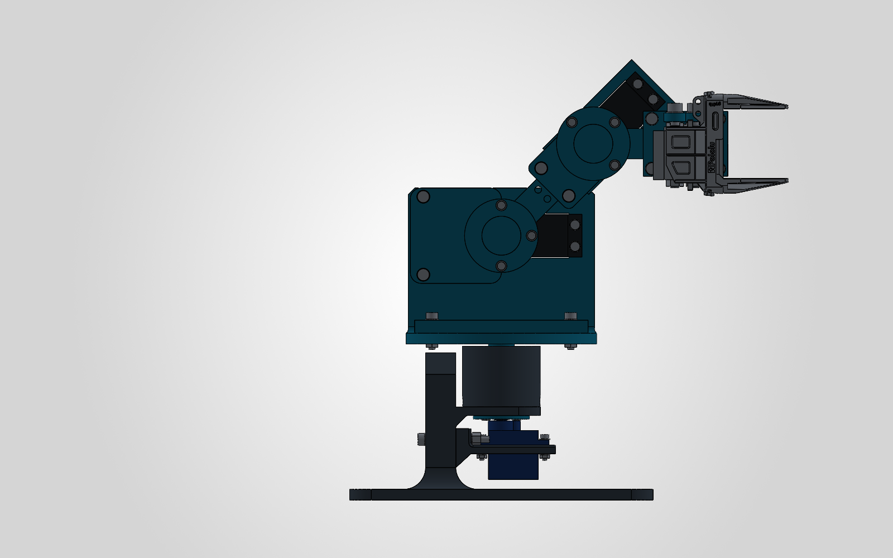
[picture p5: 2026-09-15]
cad/arm-v4/review-images/front.bmp

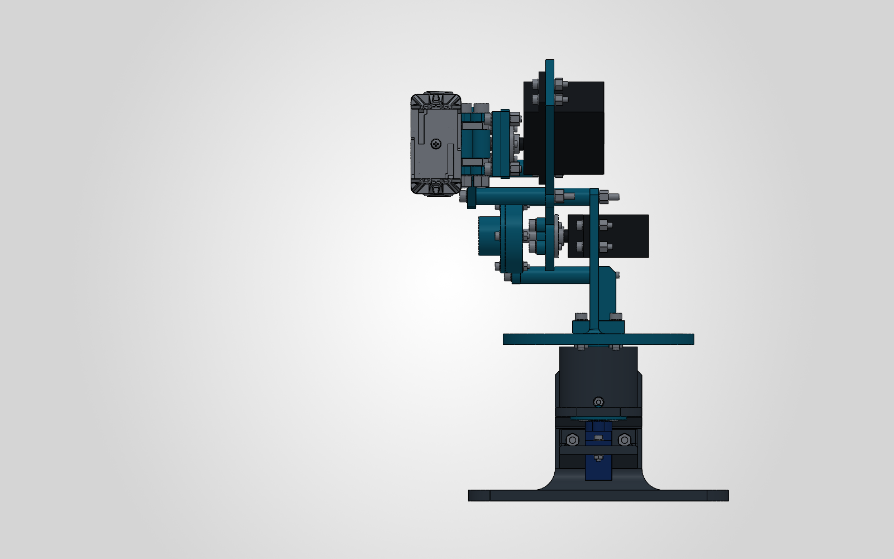
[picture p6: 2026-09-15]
cad/arm-v4/review-images/right.bmp

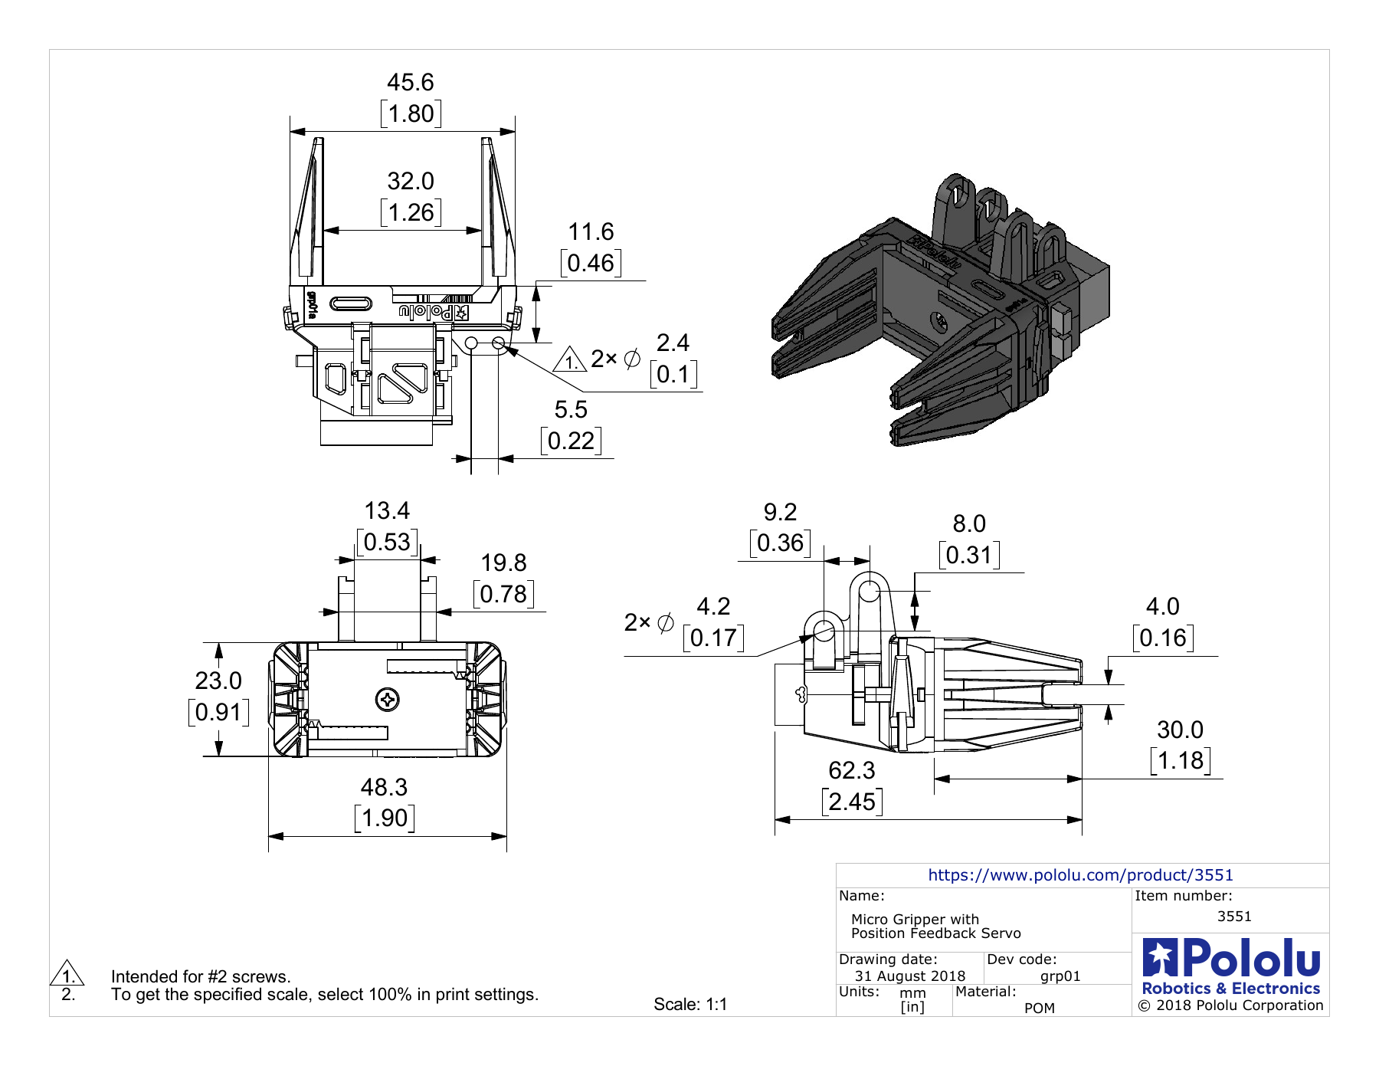
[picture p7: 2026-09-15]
cad/arm-v4/source-reference/pololu-3551-dimensions.png

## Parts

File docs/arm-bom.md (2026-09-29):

# Articulated arm D — hardware and budget

Development BOM, 2026-09-28 (owned-servo update). Native assembly: **191 active components, 44 fastener stacks, 24 printed pieces across 15 types**. 75 superseded nominal-servo components stay in the model, suppressed. This is a development model, not a print release. No purchases were made by the agent. Revision C documents are preserved in `cad/arm-v4/development-debug`.

## Owned hardware to reuse

- **Two MG996R positional servos** — shoulder (in ARM-203) and elbow (in ARM-201). Recorded purchase cost: **$10 total**. Geometry: `cad/arm-v4/parts/MG996R_servo.SLDPRT`.
- **Four SG90 micro servos** — one drives yaw (ARM-004 cassette, ARM-003 collar). The other three are spares, deliberately unused (see `HANDOFF.md`). Geometry for all four: `cad/arm-v4/parts/SERVO_SG90.SLDPRT`.
- **Four 608ZZ bearings**, 8 × 22 × 7 mm. Keep a fifth as the pick object.
- **Two 6.35 × 25.4 mm dowel pins**, plus the existing Mega R3 and signal cables.
- **Each servo's own horn (centre) screw.** SG90: its small M2 self-tapping horn screw, about 4 mm long (modeled as M2 × 4 pan head, Ø4.0 × 1.6). MG996R: use the original M3 horn screw only if its head is ≤ Ø6.0 × 2.0 mm and it engages at least 5 mm. Otherwise use the M3 × 8 low-head screws listed below.

No servo horns are used. Neither servo file contains horn geometry, so the joints drive straight off the splines through printed parts.

## Additions

- **One [Pololu 3551 micro parallel gripper](https://www.pololu.com/product/3551)**, including its FS90-FB feedback servo: **$29.95**, checked 2026-09-12. The supplier showed backorders; confirm delivery before printing ARM-205.
- **One external regulated 5 V supply**, unless a suitable bench supply is available. [Adafruit 658, 5 V/10 A](https://www.adafruit.com/product/658): **$29.95**, shown in stock on 2026-09-12. Supply capacity alone does not rate the downstream connector or wiring.
- Distribution, wire, fuse/protection and an accessible DC disconnect: **$15–25** allowance.
- Fastener packs and spares below: **$35–55** allowance. The only special parts are two M3 × 8 low-head (DIN 7984) screws and eight plain M3 hex nuts.
- PETG and fit prints: **$10–25**. Optional small rubber gripping liners: **$1–5**. Bench clamps: **$0–10**. Ties and consumables: **$5–10**.
- **Removed from the earlier D list:** the two OD20/PCD14 metal horns ($10–20), the M2 × 10 low-profile (Ø4 × 1.1) cap screws, and all M2.5 servo-ear hardware.

## Fasteners — native assembly quantities

All lengths are under the head. The models omit threads and sockets. Do not substitute longer screws without checking the assembly.

- **9 × Nut M2 hex**
- **8 × Nut M3 hex**
- **22 × Nut M3 nyloc**
- **2 × Nut M4 nyloc**
- **2 × Screw M2x10 socket**
- **6 × Screw M2x14 socket**
- **1 × Screw M2x20 socket**
- **1 × Screw M2x4 PAN HEAD D4 H1p6**
- **8 × Screw M3x12 socket**
- **16 × Screw M3x14 socket**
- **2 × Screw M3x30 socket**
- **4 × Screw M3x50 socket**
- **2 × Screw M3x8 LOW HEAD D5p5 H2**
- **2 × Screw M4x35 socket**
- **14 × Washer M2 washer 0p5**
- **52 × Washer M3 washer 0p5**
- **4 × Washer M4 washer 0p5**

Where they go:

- **16 × M3 × 14** — eight MG996R ear stacks (two washers and a nyloc each), four upright-to-platform, four tool-adapter.
- **8 × M3 × 12** — link to ARM-207 hub on an 18 mm bolt circle (one washer each), into **8 plain M3 hex nuts** captured 0.5 mm deep in the hub pockets.
- **2 × M3 × 8 low head** — hub to MG996R spline, into the spline's M3 thread; 7.0 mm engaged of 8.19 mm available.
- **4 × M3 × 50** — cheek standoffs. **2 × M3 × 30** — yaw cassette.
- **2 × M2 × 10** — SG90 ears, with the nut directly under the shelf and **no washers** (the hole centres are 2.4 mm from the case walls).
- **1 × M2 × 4 pan head** — the SG90's own horn screw through the ARM-003 floor.
- **6 × M2 × 14** — bearing keepers. **1 × M2 × 20** — yaw crossbolt.
- **2 × M4 × 35** — gripper axes.

Washers are the modeled **0.5 mm small-series** types: M2 OD5/ID2.2, M3 OD6/ID3.2, M4 OD8/ID4.2. Nyloc envelopes: M3 AF5.5/H4, M4 AF7/H5. Plain nuts: M2 AF4/H1.6, M3 AF5.5/H2.4. Kit-internal gripper hardware is separate from these 44 modeled stacks.

## Printed pieces

- 1 × ARM-001_Base_pedestal
- 1 × ARM-003_Yaw_D_drive_collar
- 1 × ARM-004_Removable_yaw_servo_mount
- 1 × ARM-104_Elbow_bearing_cheek
- 1 × ARM-105_Shoulder_bearing_cheek
- 4 × ARM-107_Dowel_to_608_adapter
- 4 × ARM-108_M3_standoff_32mm
- 2 × ARM-109_Bearing_and_dowel_keeper
- 1 × ARM-201_Upper_link_dual_MG996R
- 1 × ARM-202_Yaw_platform
- 1 × ARM-203_Bolted_shoulder_upright
- 1 × ARM-204_Modular_forearm_MG996R
- 1 × ARM-205_Parallel_gripper_fork_adapter
- 2 × ARM-206_Gripper_lug_crush_spacer_13mm
- 2 × ARM-207_MG996R_printed_spline_hub

Fit coupons, printed first: FIT-001_Dowel_and_bearing_trial, FIT-003_MG996R_spline_socket_trial, FIT-004_SG90_spline_socket_trial.

**Superseded — do not print or buy for D:** ARM-112 horn cap and its four low-head screws, washers and nuts; FIT-002 horn-pocket coupons; HW-006 metal horns; HW-003/HW-004/HW-005 nominal servo and horn envelopes; M2.5 ear hardware. They remain in `parts`/`hardware-reference` and as suppressed components; curated exports are in `fabrication-trial/superseded-2026-09-28`.

## Budget and buying order

The additions total **$125.90–189.90**, before shipping/tax and contingency. With $20–25 shipping/tax and $20–30 contingency, that is **$165.90–244.90 remaining spend**, if none of those additions is already on hand. Adding the earlier recorded $20.17 SG90/bearing/dowel order and the $10 MG996R pair gives **$196.07–275.07 estimated all-in cost**. Existing Mega/kit costs are excluded as sunk costs. These are pack and printing allowances, not a checkout quote.

Buying order:

1. Print FIT-003, FIT-004 and FIT-001, and test them on the owned servos, a bearing and a dowel.
2. Confirm gripper stock.
3. Order the fasteners.
4. Print one structural set.

Reuse workshop power and clamps where suitable to stay near the historical $250 target. Avoid duplicate motors or a new controller.

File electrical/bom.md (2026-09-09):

# Bill of Materials

| Item | Part # | Qty | Cost | Status | Link |
|---|---|---|---|---|---|
| ELEGOO Mega R3 (Arduino-compatible) | - | 1 | $0 (owned) | In hand | |
| SG90 Servo (gripper open/close) | - | 1 | $0 (owned) | In hand | |
| SG90 Servo (EOAT Z stroke) | - | 1–2 | ~$7 (4-pack) | Ordered 2026-09-03, ETA ~Sat 9/5 | Amazon 4-pack (~$6.99). Kit SG90 remains gripper. Not a gantry axis. |
| Breadboard + jumper wires | - | 1 set | $0 (owned) | In hand | |
| Skate bearing (pick object) | 608ZZ | 20 | ~$5.59 | Ordered 2026-09-03, ETA ~Sat 9/5 | Amazon 20-pack, 8×22×7 mm. Extras for drop tests. |
| Steel dowel pin (Phase 1 locating pin) | 1/4" × 1" | 15 | ~$7.59 | Ordered 2026-09-03, ETA ~Sat 9/5 | 1/4" × 1" alloy. 6.35 mm OD vs 8 mm bore → known slip clearance. One nest pin + spares. |
| Allen-Bradley Micro820 PLC | 2080-LC20-20QWB | 1 | ~$200–400 typical | Do not buy yet | Check WashU loan / CCW access first. Not part of the $250 cell budget. |
| NEMA17 Stepper | | 1 powered (kit may include 3) | | Not ordered | Phase 1–2: drive **one** axis only |
| TB6600 Driver | | 1 powered (kit may include 3) | | Not ordered | Do not wire extra drivers until Phase 3 |
| 24V Power Supply | | 1 | | Not ordered | |
| Inductive Proximity Sensor | | 2 | | Not ordered | |
| Limit Switch | | 4 | | Not ordered | |
| V-slot Gantry Kit | | 1 | | Not ordered | One powered X axis for Phase 1–2. Unused kit axes stay unpowered. Z is the EOAT servo, not gantry Z. |

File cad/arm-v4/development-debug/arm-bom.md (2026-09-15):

# Articulated arm C — hardware and budget

Development BOM, 2026-09-08. Quantities below describe Revision C; verify against the final native assembly report before ordering. Nothing has been purchased by the agent. The historical $250 cell budget is a planning target; Luis explicitly prioritized useful functional improvements over a rigid ceiling.

**Revision C count verification:** the saved native assembly has 190 components, 24 printed instances across 16 part types, and 43 fastener stacks. Component counts match the quantities below. The shoulder targets an OD20 / PCD14 metal horn; three printed caps capture the unmodified SG90 cross horns. Actual seated-horn height, cap clearance and the selected shoulder horn still require fit confirmation; see [the assembly guide](arm-print-and-assembly-guide.md). These are verified CAD quantities, not an unconditional ordering release.

## Reuse the purchased hardware

- **3 SG90 positional servos:** base yaw, elbow, and gripper. Retain the matching stock horns and three original horn center screws. The ordered four-pack plus the existing kit servo provides spares.
- **4 × 608ZZ bearings, 8 × 22 × 7 mm:** two in the yaw tower, one in the shoulder support, one in the elbow support. Reserve a fifth bearing as the demonstration payload.
- **2 × 6.35 × 25.4 mm steel dowels:** passive shoulder and elbow support pins. Printed adapters accommodate the 8 mm bearing bores. The earlier BOM records a 15-pack.
- **1 ELEGOO Mega R3**, its USB cable, and low-current signal jumpers. Servo power requires separate distribution.
- Historical order estimate: SG90 pack $6.99 + bearing pack $5.59 + dowel pack $7.59 = **$20.17 already allocated**. Existing Mega/kit cost is treated as sunk cost, not a new purchase.

## Required additions

- **1 MG996R positional shoulder servo**, with compatible horn and original center screw. Allow **$15–30**, pending the actual supplier quote. Measure the purchased unit before printing its mount. Reference dimensions and torque come from [TowerPro](https://towerpro.com.tw/product/mg996r/); this is not a promise that an unverified clone matches those values.
- **1 regulated external 5 V supply.** Preferred planning option: [Adafruit 5 V 10 A supply, product 658](https://www.adafruit.com/product/658), **$29.95 listed on 2026-09-07**, excluding shipping/tax. Extra current capacity provides room for startup peaks; it does not establish the actual motor current or validate the wiring. An existing regulated bench supply can replace this purchase during commissioning.
- **Power distribution, accessible DC disconnect, correctly rated connector, wire, and fuse holder/fuse:** allow **$15–25**. Match protection to the smallest wire/connector rating and confirm simultaneous current during tests. Keep the servo load off the Mega regulator and solderless breadboard rails. Connect signal ground to the servo supply ground.
- **Machine screws, nuts, washers:** allow **$35–55** for purchasable packs and spares, rather than pricing only individual screws. Quantities and dimensions follow below. The M2.5 shoulder-ear hardware is intentional: larger nut corners can contact the servo case.
- **PETG structural prints and fit coupons:** allow **$10–25** for material/print access, pending the makerspace quote. This is an allowance, not a slicer-derived cost.
- **Two small TPU jaw pads:** allow **$5–15** for a shared-material print. A whole spool, if required, changes this estimate. The pads are captured with screws; adhesive is not the sole retention method.
- **Bench fixture/clamps and catch surface:** allow **$0–10** if workshop clamps or scrap board are available. Base holes are 5.5 mm clearance; fixture bolt length depends on the actual board/bench thickness.
- **Cable ties, sleeve-retention consumables and miscellaneous small parts:** allow **$5–10**. Keep any sleeve adhesive away from the bearing races; fit and retention must be checked first.

## Exact arm fastener quantities

All lengths are under-head lengths. Screw models omit threads and drive sockets. Use matching thread pitches and verify the supplied horn attachment holes. Original servo center screws are separate from these counts.

- **M2 × 10 low-profile screws: 12** — four per SG90 horn cap. Maximum modeled head dimensions: 4 mm diameter × 1.1 mm height. These are distinct from ordinary socket screws; confirm a purchasable matching head and re-quote the pack cost.
- **M2 × 10 socket screws: 8** — six SG90 mounting-ear screws and two fixed-pad capture screws.
- **M2 × 14 socket screws: 6** — three per passive bearing keeper.
- **M2 × 20 socket screw: 1** — yaw spindle/collar crossbolt.
- **M2 × 30 socket screws: 2** — moving-pad capture through the taller C finger.
- **M2 plain hex nuts: 29**, nominal 4 mm across flats × 1.6 mm high.
- **M2 washers: 46**, nominal 2.2 mm ID × 5 mm OD × 0.5 mm thick. Each horn-cap bolt uses one front washer; the other M2 stacks use two.
- **M2.5 × 14 socket screws: 4** — shoulder servo ears.
- **M2.5 nylon-insert nuts: 4**, maximum modeled 5 mm across flats × 3.5 mm high; verify the actual supplier dimensions. See [manufacturer dimension reference](https://www.jcfasteners.com/wp-content/uploads/DIN-985-Nylock-Nut-THIN-A2C34-MS-ZN.pdf).
- **M2.5 small-series washers: 8**, 2.7 mm ID × 5 mm OD × 0.5 mm thick. See [manufacturer/supplier dimensions](https://www.vital-parts.co.uk/washers-for-cheese-heads-din-433/31341-w433-m25-a2).
- **M3 × 12 socket screws: 4** — shoulder horn.
- **M3 × 30 socket screws: 2** — removable yaw servo cassette.
- **M3 × 45 socket screws: 2** — 28.6 mm C elbow support standoffs.
- **M3 × 50 socket screws: 2** — shoulder support standoffs.
- **M3 nylon-insert nuts: 6** for the structural standoffs and cassette. The four shoulder-horn screws thread into the metal horn and use no separate nuts.
- **M3 small-series washers: 16**, 3.2 mm ID × 6 mm OD × 0.5 mm thick. Standard larger washers do not fit every modeled location. See [steel washer dimension reference](https://www.ettinger.de/en/product-datasheet/f891308e688fe98aa3fc3e33a869b97d/create).
- **Original servo horn center screws: 4**, matched to each purchased servo; their thread and engagement are not guessed from the reference envelopes.

## Budget position

The additions above total **$114.95–199.95** before shipping/tax and contingency. Add **$20–25** for shipping/tax and **$20–30** contingency. Including the recorded $20.17 hardware order gives **$175.12–275.12 total**. Most lines are planning allowances; the supply is the only fixed live quote used here.

Reserve **$5–10** for the separate compatible metal shoulder horn, bringing the planning envelope to **$180.12–285.12**. This remains a planning estimate. The C cap design requires twelve low-profile M2 screws; their pack price and availability must fit the hardware allowance or the estimate must be revised. No new supplier quotes were obtained for this revision.

## Purchase sequence

1. Reuse the owned SG90s, bearings, dowels and Mega. Print and fit the bearing/dowel coupon and one horn-cap trial first.
2. Source the positional MG996R and matching OD20 / PCD14 25T metal horn together, confirming the actual dimensions. A regulated 5 V supply and suitable power distribution can be sourced independently of the final printed fits.
3. After the horn trial and native C assembly checks pass, order the final fastener pack quantities above. Check the low-profile M2 heads specifically and include a few spare screws/nuts.
4. Print one set of structural PETG parts and TPU pads, then run unloaded and incremental-load commissioning before ordering duplicate print sets or upgrades.

Aim near $230–250 by consolidating hardware orders and using the makerspace's small quantities of material. Keep useful power and joint-support improvements if their actual quotes push the project slightly over that target. Requote before buying: the final total depends heavily on fastener pack sizes, printing fees and shipping.

The current arm does not require a gantry kit, stepper drivers, or a new PLC. A future PLC is outside this arm estimate, consistent with the earlier project budget. No new electronics board is required solely to generate four servo signals from the existing Mega.

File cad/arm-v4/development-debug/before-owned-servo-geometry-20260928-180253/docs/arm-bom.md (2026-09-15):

# Articulated arm D — hardware and budget

Development BOM, 2026-09-12. Native assembly: **198 components, 45 fastener stacks, 23 printed pieces across 15 types**. Purchasing/fabrication remains conditional on actual hardware fit. No purchases were made by the agent. Revision C documents are preserved in `cad/arm-v4/development-debug`.

## Owned hardware to reuse

- **Two MG996R positional servos:** shoulder and elbow. Both are already owned; recorded purchase cost: **$10 total**. Do not buy another pair.
- **One SG90:** yaw, using its small equal-arm cross horn. Retain the other SG90s as spares.
- **Four 608ZZ bearings**, 8 × 22 × 7 mm. Reserve a fifth as a demonstration object.
- **Two 6.35 × 25.4 mm dowel pins**, plus the existing Mega R3 and signal cables.
- Keep the original horn-center screws belonging to each servo. They are not interchangeable generic screws.

## Additions

- **One [Pololu 3551 micro parallel gripper](https://www.pololu.com/product/3551)**, including its feedback servo: **$29.95** checked 2026-09-12. Supplier showed backorders; confirm delivery before printing its adapter. Official CAD is saved locally. This replaces C's printed fixed/moving fingers and their SG90.
- **Two compatible metal horns:** nominal 25T, OD20, four M3-tapped holes on PCD14, 2 mm plate with 2.5 mm rear hub. Allow **$10–20 total**. Confirm the actual horn drawing and seating on your MG996Rs; the provided plastic horns are not equivalent.
- **One external regulated 5 V supply**, unless a suitable bench supply is available. [Adafruit 658, 5 V/10 A](https://www.adafruit.com/product/658): **$29.95**, shown in stock on 2026-09-12. Supply capacity alone does not rate the downstream connector or wiring.
- Distribution, wire, fuse/protection and accessible DC disconnect: **$15–25** allowance.
- Fastener packs/spares below: **$35–55** allowance; quote the low-profile M2 screws and M3×14 specifically.
- PETG and fit prints: **$10–25**; optional small rubber gripping liners: **$1–5**; bench clamps: **$0–10**; ties/consumables: **$5–10**.

## Fasteners — native assembly quantities

All lengths are under the head. Models omit threads and sockets. Do not substitute longer screws without checking the assembly.

- **8 × Nut M2.5 nyloc**
- **13 × Nut M2 hex**
- **14 × Nut M3 nyloc**
- **2 × Nut M4 nyloc**
- **8 × Screw M2.5x14 socket**
- **4 × Screw M2x10 LOW HEAD D4 H1p1**
- **2 × Screw M2x10 socket**
- **6 × Screw M2x14 socket**
- **1 × Screw M2x20 socket**
- **8 × Screw M3x12 socket**
- **8 × Screw M3x14 socket**
- **2 × Screw M3x30 socket**
- **4 × Screw M3x50 socket**
- **2 × Screw M4x35 socket**
- **16 × Washer M2.5 washer 0p5**
- **22 × Washer M2 washer 0p5**
- **36 × Washer M3 washer 0p5**
- **4 × Washer M4 washer 0p5**

M2 low-profile heads must be no larger than Ø4 × 1.1 mm; four are needed for the yaw horn cap. Ordinary socket heads do not fit that clearance. Washers are the modeled **0.5 mm small-series** types: M2 OD5/ID2.2, M2.5 OD5/ID2.7, M3 OD6/ID3.2, M4 OD8/ID4.2. Nyloc envelopes: M2.5 AF5/H3.5, M3 AF5.5/H4, M4 AF7/H5. Match these dimensions before ordering.

The eight M3×14 screws divide between the four recessed-nut upright mounts and four tool-adapter mounts. Eight M3×12 screws fasten the two metal horns. Four M3×50 screws support the shoulder/elbow cheeks. Two M3×30 mount the yaw cassette. Two M4×35 retain the gripper on its fork. Kit-internal gripper hardware and the original servo center screws are separate from these 45 modeled stacks.

## Printed pieces

- 1 × ARM-001_Base_pedestal
- 1 × ARM-003_Yaw_D_drive_collar
- 1 × ARM-004_Removable_yaw_servo_mount
- 1 × ARM-104_Elbow_bearing_cheek
- 1 × ARM-105_Shoulder_bearing_cheek
- 4 × ARM-107_Dowel_to_608_adapter
- 4 × ARM-108_M3_standoff_32mm
- 2 × ARM-109_Bearing_and_dowel_keeper
- 1 × ARM-112_SG90_horn_capture_cap
- 1 × ARM-201_Upper_link_dual_MG996R
- 1 × ARM-202_Yaw_platform
- 1 × ARM-203_Bolted_shoulder_upright
- 1 × ARM-204_Modular_forearm_MG996R
- 1 × ARM-205_Parallel_gripper_fork_adapter
- 2 × ARM-206_Gripper_lug_crush_spacer_13mm

## Budget and buying order

The additions total **$135.90–209.90**, before shipping/tax and contingency. Allowing $20–25 shipping/tax and $20–30 contingency gives **$175.90–264.90 remaining spend** if none of those additions is already available. Including the earlier recorded $20.17 SG90/bearing/dowel order and the $10 MG996R pair gives **$206.07–295.07 estimated all-in cost**. Existing Mega/kit costs are excluded as sunk costs. These are pack/printing allowances, not a checkout quote.

Confirm gripper stock and metal-horn geometry first. Print small horn/bearing/dowel trials next. Then order the final fasteners and one structural set. Reuse workshop power/clamps when suitable to stay near the historical $250 target. The user allows worthwhile functional improvements beyond that target; avoid duplicate motors or a new controller.

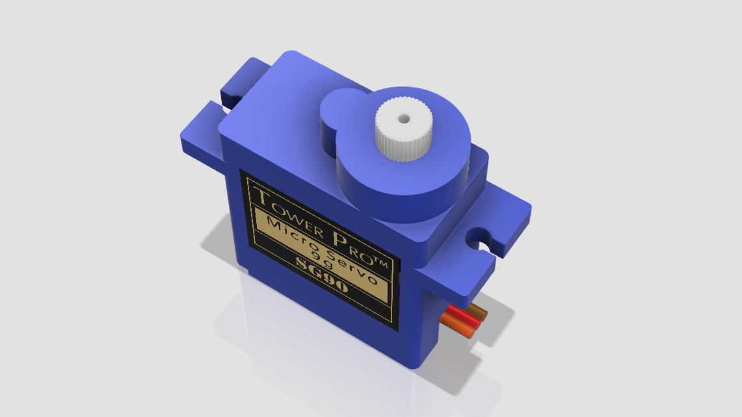
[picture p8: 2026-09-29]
cad/arm-v4/parts/SERVO_SG90_2.png

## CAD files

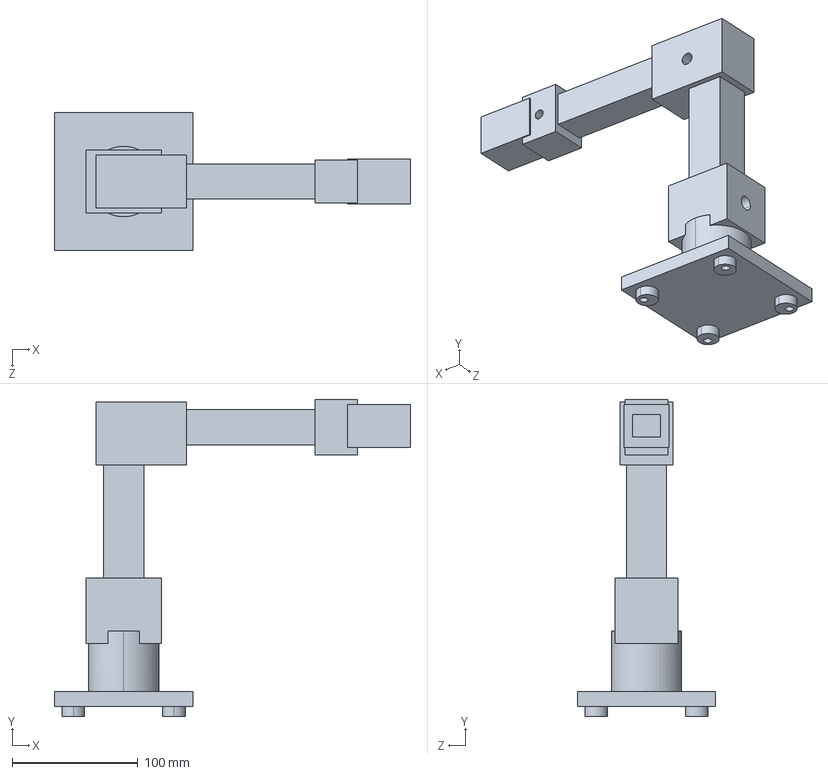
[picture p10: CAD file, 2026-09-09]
cad/_sw_agent_test/agent_desk_arm.step
283.0 x 252.0 x 110.0 mm

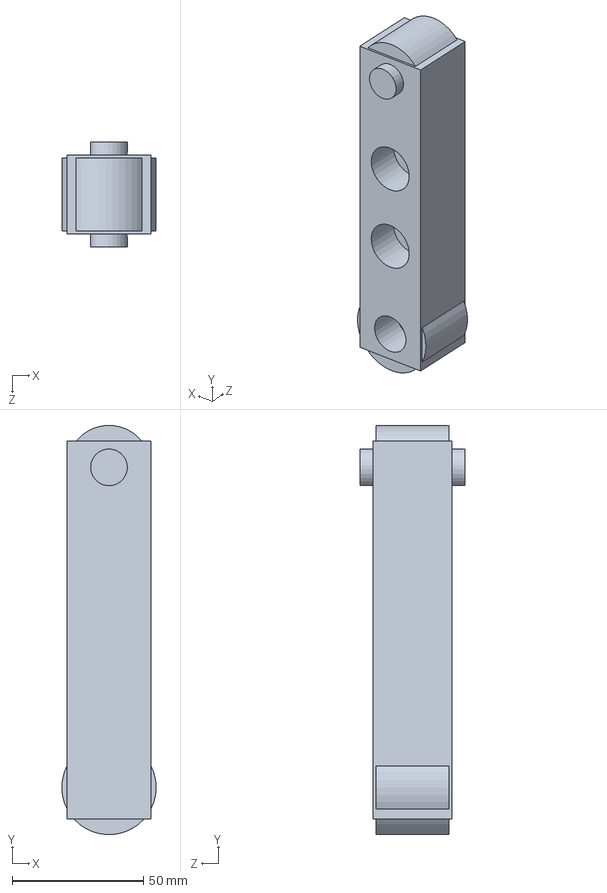
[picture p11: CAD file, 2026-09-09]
cad/_sw_agent_test/arm_motion/03_upper_arm.SLDPRT
36.0 x 155.9 x 40.0 mm

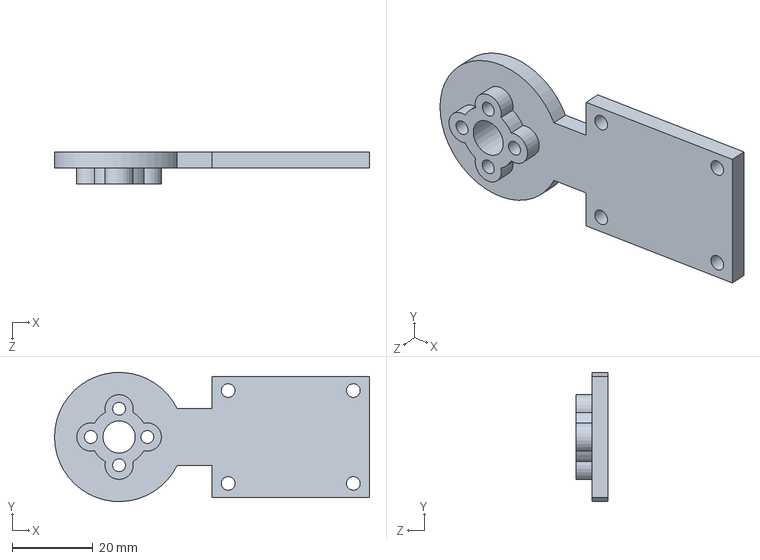
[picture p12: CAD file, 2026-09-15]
cad/arm-v4/development-debug/before-sketch-constraints-20260912-215649/ARM-204_Modular_forearm_MG996R.SLDPRT
78.0 x 32.0 x 8.00 mm

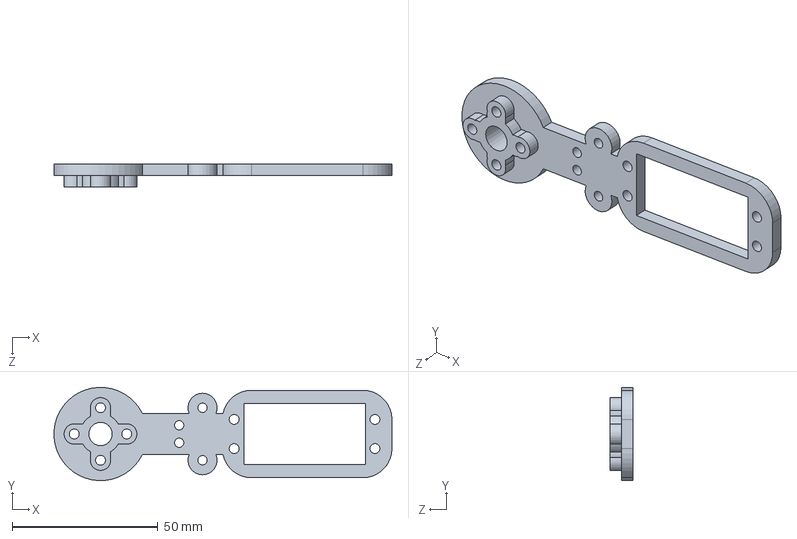
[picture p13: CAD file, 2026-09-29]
cad/arm-v4/development-debug/before-sketch-constraints-20260928-181539/ARM-201_Upper_link_dual_MG996R.SLDPRT
116.0 x 32.0 x 8.00 mm

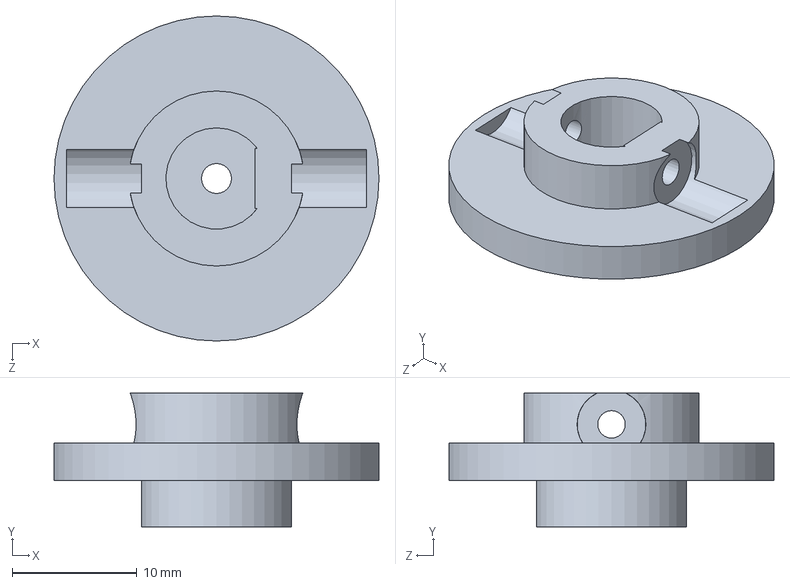
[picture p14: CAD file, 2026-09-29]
cad/arm-v4/development-debug/before-sketch-constraints-20260928-181639/ARM-003_Yaw_D_drive_collar.SLDPRT
26.0 x 10.7 x 26.0 mm

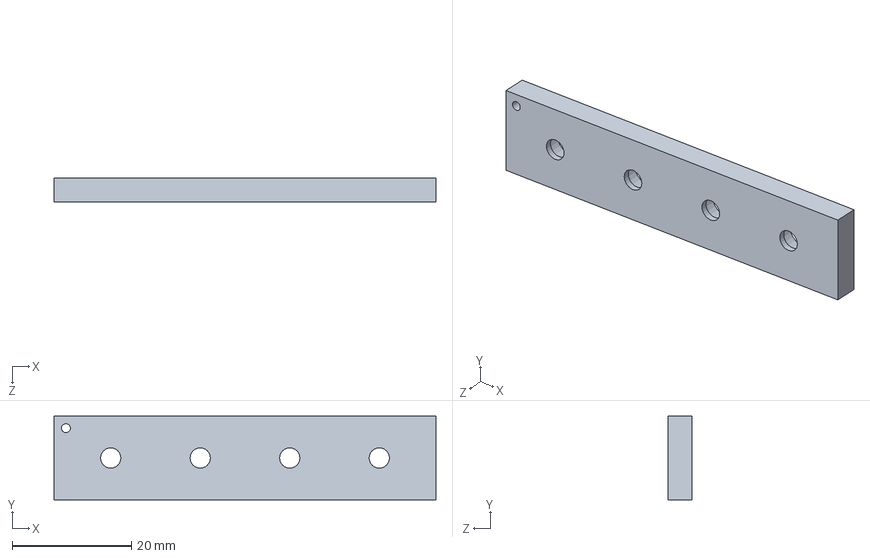
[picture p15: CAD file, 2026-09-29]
cad/arm-v4/development-debug/before-sketch-constraints-20260928-181701/FIT-003_MG996R_spline_socket_trial.SLDPRT
64.0 x 14.0 x 4.00 mm

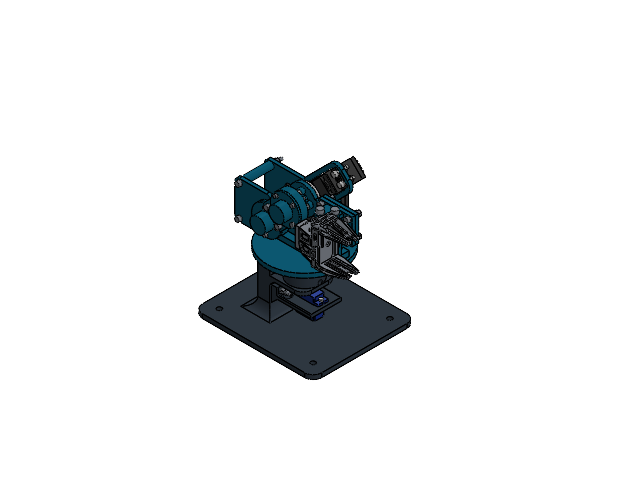
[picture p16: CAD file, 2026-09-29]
cad/arm-v4/ARM-D_Modular_parallel_gripper_DEVELOPMENT.SLDASM
ARM-001_Base_pedestal
ARM-202_Yaw_platform
ARM-003_Yaw_D_drive_collar
HW-001_608ZZ_22x8x7_ENVELOPE x 4
ARM-201_Upper_link_dual_MG996R
ARM-204_Modular_forearm_MG996R
ARM-004_Removable_yaw_servo_mount
ARM-203_Bolted_shoulder_upright
ARM-105_Shoulder_bearing_cheek
ARM-109_Bearing_and_dowel_keeper x 2
HW-002_Dowel_6p35x25p4 x 2
ARM-107_Dowel_to_608_adapter x 4
ARM-108_M3_standoff_32mm x 4
ARM-104_Elbow_bearing_cheek
ARM-205_Parallel_gripper_fork_adapter
HW-203_Pololu3551_jaw x 2
HW-202_Pololu3551_body
ARM-206_Gripper_lug_crush_spacer_13mm x 2
HW-S_M3x14_socket_ENVELOPE x 16
HW-W_M3_washer_0p5_ENVELOPE x 52
HW-N_M3_nyloc_ENVELOPE x 22
HW-S_M4x35_socket_ENVELOPE x 2
HW-W_M4_washer_0p5_ENVELOPE x 4
HW-N_M4_nyloc_ENVELOPE x 2
HW-S_M3x50_socket_ENVELOPE x 4
HW-S_M2x14_socket_ENVELOPE x 6
HW-W_M2_washer_0p5_ENVELOPE x 14
HW-N_M2_hex_ENVELOPE x 9
HW-S_M2x20_socket_ENVELOPE
HW-S_M3x30_socket_ENVELOPE x 2
MG996R_servo x 2
SERVO_SG90
ARM-207_MG996R_printed_spline_hub x 2
HW-S_M3x8_LOW_HEAD_D5p5_H2_ENVELOPE x 2
HW-S_M2x4_PAN_HEAD_D4_H1p6_ENVELOPE
HW-S_M3x12_socket_ENVELOPE x 8
HW-N_M3_hex_ENVELOPE x 8
HW-S_M2x10_socket_ENVELOPE x 2

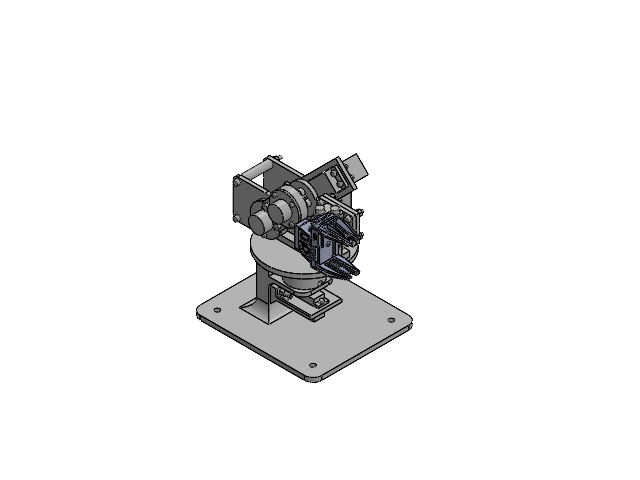
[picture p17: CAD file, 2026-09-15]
cad/arm-v4/development-debug/before-clearance-corrections/ARM-D_Modular_parallel_gripper_DEVELOPMENT.SLDASM
ARM-001_Base_pedestal
ARM-202_Yaw_platform
ARM-003_Yaw_D_drive_collar
HW-003_SG90_NOMINAL_VERIFY
HW-001_608ZZ_22x8x7_ENVELOPE x 4
HW-004_MG996R_NOMINAL_VERIFY x 2
ARM-201_Upper_link_dual_MG996R
ARM-204_Modular_forearm_MG996R
ARM-004_Removable_yaw_servo_mount
ARM-203_Bolted_shoulder_upright
HW-005_SG90_COMPACT_CROSS_REFERENCE
HW-006_MG996_25T_D20_PCD14_HORN x 2
ARM-112_SG90_horn_capture_cap
ARM-105_Shoulder_bearing_cheek
ARM-109_Bearing_and_dowel_keeper x 2
HW-002_Dowel_6p35x25p4 x 2
ARM-107_Dowel_to_608_adapter x 4
ARM-108_M3_standoff_32mm x 4
ARM-104_Elbow_bearing_cheek
ARM-205_Parallel_gripper_fork_adapter
HW-203_Pololu3551_jaw x 2
HW-202_Pololu3551_body
ARM-206_Gripper_lug_crush_spacer_13mm x 2
HW-S_M2x10_socket_ENVELOPE x 2
HW-W_M2_washer_0p5_ENVELOPE x 22
HW-N_M2_hex_ENVELOPE x 13
HW-S_M2.5x14_socket_ENVELOPE x 8
HW-W_M2.5_washer_0p5_ENVELOPE x 16
HW-N_M2.5_nyloc_ENVELOPE x 8
HW-S_M3x20_socket_ENVELOPE x 4
HW-W_M3_washer_0p5_ENVELOPE x 36
HW-N_M3_nyloc_ENVELOPE x 14
HW-S_M3x16_socket_ENVELOPE x 4
HW-S_M4x35_socket_ENVELOPE x 2
HW-W_M4_washer_0p5_ENVELOPE x 4
HW-N_M4_nyloc_ENVELOPE x 2
HW-S_M3x50_socket_ENVELOPE x 4
HW-S_M2x14_socket_ENVELOPE x 6
HW-S_M3x12_socket_ENVELOPE x 8
HW-S_M2x10_LOW_HEAD_D4_H1p1_ENVELOPE x 4
HW-S_M2x20_socket_ENVELOPE
HW-S_M3x30_socket_ENVELOPE x 2

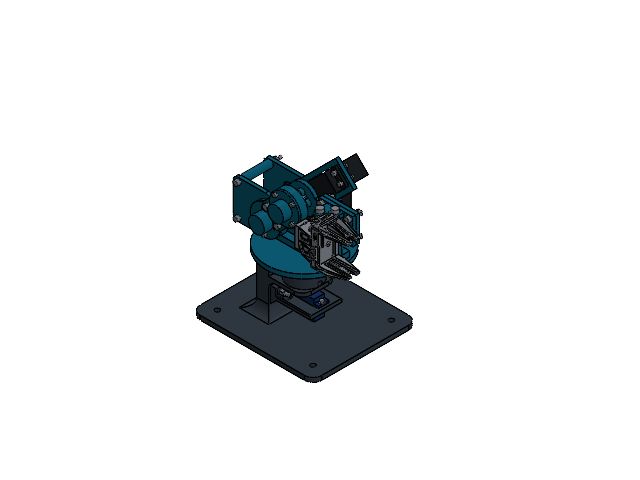
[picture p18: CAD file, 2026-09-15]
cad/arm-v4/development-debug/before-limited-motion-20260912-215630/ARM-D_Modular_parallel_gripper_DEVELOPMENT.SLDASM
ARM-001_Base_pedestal
ARM-202_Yaw_platform
ARM-003_Yaw_D_drive_collar
HW-003_SG90_NOMINAL_VERIFY
HW-001_608ZZ_22x8x7_ENVELOPE x 4
HW-004_MG996R_NOMINAL_VERIFY x 2
ARM-201_Upper_link_dual_MG996R
ARM-204_Modular_forearm_MG996R
ARM-004_Removable_yaw_servo_mount
ARM-203_Bolted_shoulder_upright
HW-005_SG90_COMPACT_CROSS_REFERENCE
HW-006_MG996_25T_D20_PCD14_HORN x 2
ARM-112_SG90_horn_capture_cap
ARM-105_Shoulder_bearing_cheek
ARM-109_Bearing_and_dowel_keeper x 2
HW-002_Dowel_6p35x25p4 x 2
ARM-107_Dowel_to_608_adapter x 4
ARM-108_M3_standoff_32mm x 4
ARM-104_Elbow_bearing_cheek
ARM-205_Parallel_gripper_fork_adapter
HW-203_Pololu3551_jaw x 2
HW-202_Pololu3551_body
ARM-206_Gripper_lug_crush_spacer_13mm x 2
HW-S_M2x10_socket_ENVELOPE x 2
HW-W_M2_washer_0p5_ENVELOPE x 22
HW-N_M2_hex_ENVELOPE x 13
HW-S_M2.5x14_socket_ENVELOPE x 8
HW-W_M2.5_washer_0p5_ENVELOPE x 16
HW-N_M2.5_nyloc_ENVELOPE x 8
HW-S_M3x14_socket_ENVELOPE x 8
HW-W_M3_washer_0p5_ENVELOPE x 36
HW-N_M3_nyloc_ENVELOPE x 14
HW-S_M4x35_socket_ENVELOPE x 2
HW-W_M4_washer_0p5_ENVELOPE x 4
HW-N_M4_nyloc_ENVELOPE x 2
HW-S_M3x50_socket_ENVELOPE x 4
HW-S_M2x14_socket_ENVELOPE x 6
HW-S_M3x12_socket_ENVELOPE x 8
HW-S_M2x10_LOW_HEAD_D4_H1p1_ENVELOPE x 4
HW-S_M2x20_socket_ENVELOPE
HW-S_M3x30_socket_ENVELOPE x 2

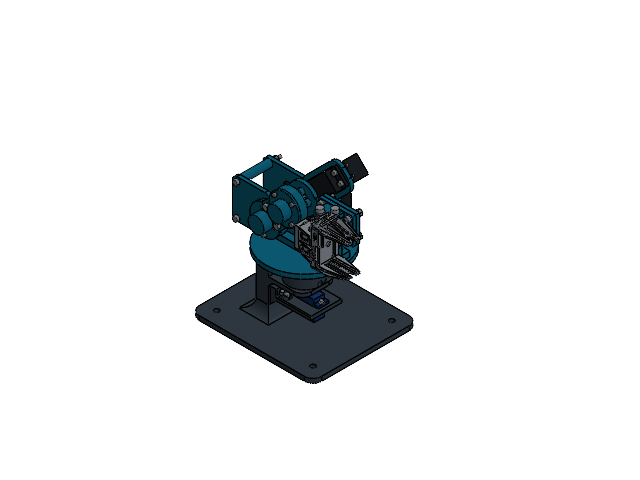
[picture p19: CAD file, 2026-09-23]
cad/arm-v4/development-debug/before-owned-servo-geometry-20260928-180253/ARM-D_Modular_parallel_gripper_DEVELOPMENT.SLDASM
ARM-001_Base_pedestal
ARM-202_Yaw_platform
ARM-003_Yaw_D_drive_collar
HW-003_SG90_NOMINAL_VERIFY
HW-001_608ZZ_22x8x7_ENVELOPE x 4
HW-004_MG996R_NOMINAL_VERIFY x 2
ARM-201_Upper_link_dual_MG996R
ARM-204_Modular_forearm_MG996R
ARM-004_Removable_yaw_servo_mount
ARM-203_Bolted_shoulder_upright
HW-005_SG90_COMPACT_CROSS_REFERENCE
HW-006_MG996_25T_D20_PCD14_HORN x 2
ARM-112_SG90_horn_capture_cap
ARM-105_Shoulder_bearing_cheek
ARM-109_Bearing_and_dowel_keeper x 2
HW-002_Dowel_6p35x25p4 x 2
ARM-107_Dowel_to_608_adapter x 4
ARM-108_M3_standoff_32mm x 4
ARM-104_Elbow_bearing_cheek
ARM-205_Parallel_gripper_fork_adapter
HW-203_Pololu3551_jaw x 2
HW-202_Pololu3551_body
ARM-206_Gripper_lug_crush_spacer_13mm x 2
HW-S_M2x10_socket_ENVELOPE x 2
HW-W_M2_washer_0p5_ENVELOPE x 22
HW-N_M2_hex_ENVELOPE x 13
HW-S_M2.5x14_socket_ENVELOPE x 8
HW-W_M2.5_washer_0p5_ENVELOPE x 16
HW-N_M2.5_nyloc_ENVELOPE x 8
HW-S_M3x14_socket_ENVELOPE x 8
HW-W_M3_washer_0p5_ENVELOPE x 36
HW-N_M3_nyloc_ENVELOPE x 14
HW-S_M4x35_socket_ENVELOPE x 2
HW-W_M4_washer_0p5_ENVELOPE x 4
HW-N_M4_nyloc_ENVELOPE x 2
HW-S_M3x50_socket_ENVELOPE x 4
HW-S_M2x14_socket_ENVELOPE x 6
HW-S_M3x12_socket_ENVELOPE x 8
HW-S_M2x10_LOW_HEAD_D4_H1p1_ENVELOPE x 4
HW-S_M2x20_socket_ENVELOPE
HW-S_M3x30_socket_ENVELOPE x 2

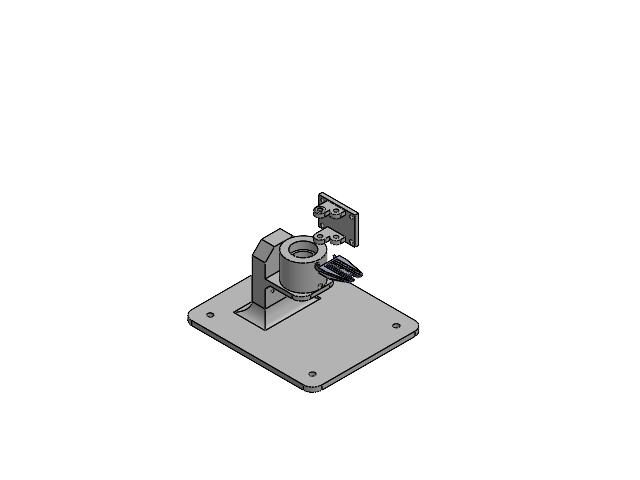
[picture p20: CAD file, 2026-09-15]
cad/arm-v4/development-debug/D_partial_insertion.SLDASM
ARM-001_Base_pedestal
ARM-202_Yaw_platform
ARM-003_Yaw_D_drive_collar
HW-003_SG90_NOMINAL_VERIFY
HW-001_608ZZ_22x8x7_ENVELOPE x 4
HW-004_MG996R_NOMINAL_VERIFY x 2
ARM-201_Upper_link_dual_MG996R
ARM-204_Modular_forearm_MG996R
ARM-004_Removable_yaw_servo_mount
ARM-203_Bolted_shoulder_upright
HW-005_SG90_COMPACT_CROSS_REFERENCE
HW-006_MG996_25T_D20_PCD14_HORN x 2
ARM-112_SG90_horn_capture_cap
ARM-105_Shoulder_bearing_cheek
ARM-109_Bearing_and_dowel_keeper x 2
HW-002_Dowel_6p35x25p4 x 2
ARM-107_Dowel_to_608_adapter x 4
ARM-108_M3_standoff_32mm x 4
ARM-104_Elbow_bearing_cheek
ARM-205_Parallel_gripper_fork_adapter
HW-203_Pololu3551_jaw x 2
HW-202_Pololu3551_body
ARM-206_Gripper_lug_crush_spacer_13mm x 2
HW-S_M2x10_socket_ENVELOPE x 2
HW-W_M2_washer_0p5_ENVELOPE x 16
HW-N_M2_hex_ENVELOPE x 8
HW-S_M2.5x14_socket_ENVELOPE x 8
HW-W_M2.5_washer_0p5_ENVELOPE x 16
HW-N_M2.5_nyloc_ENVELOPE x 8
HW-S_M3x20_socket_ENVELOPE x 4
HW-W_M3_washer_0p5_ENVELOPE x 24
HW-N_M3_nyloc_ENVELOPE x 12
HW-S_M3x16_socket_ENVELOPE x 4
HW-S_M4x35_socket_ENVELOPE x 2
HW-W_M4_washer_0p5_ENVELOPE x 4
HW-N_M4_nyloc_ENVELOPE x 2
HW-S_M3x50_socket_ENVELOPE x 4
HW-S_M2x14_socket_ENVELOPE x 6

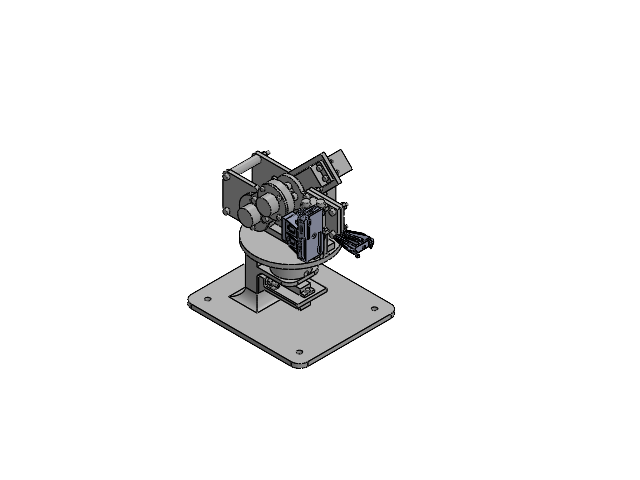
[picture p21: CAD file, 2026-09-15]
cad/arm-v4/development-debug/D_before_jaw_alignment.SLDASM
ARM-001_Base_pedestal
ARM-202_Yaw_platform
ARM-003_Yaw_D_drive_collar
HW-003_SG90_NOMINAL_VERIFY
HW-001_608ZZ_22x8x7_ENVELOPE x 4
HW-004_MG996R_NOMINAL_VERIFY x 2
ARM-201_Upper_link_dual_MG996R
ARM-204_Modular_forearm_MG996R
ARM-004_Removable_yaw_servo_mount
ARM-203_Bolted_shoulder_upright
HW-005_SG90_COMPACT_CROSS_REFERENCE
HW-006_MG996_25T_D20_PCD14_HORN x 2
ARM-112_SG90_horn_capture_cap
ARM-105_Shoulder_bearing_cheek
ARM-109_Bearing_and_dowel_keeper x 2
HW-002_Dowel_6p35x25p4 x 2
ARM-107_Dowel_to_608_adapter x 4
ARM-108_M3_standoff_32mm x 4
ARM-104_Elbow_bearing_cheek
ARM-205_Parallel_gripper_fork_adapter
HW-203_Pololu3551_jaw x 2
HW-202_Pololu3551_body
ARM-206_Gripper_lug_crush_spacer_13mm x 2
HW-S_M2x10_socket_ENVELOPE x 2
HW-W_M2_washer_0p5_ENVELOPE x 22
HW-N_M2_hex_ENVELOPE x 13
HW-S_M2.5x14_socket_ENVELOPE x 8
HW-W_M2.5_washer_0p5_ENVELOPE x 16
HW-N_M2.5_nyloc_ENVELOPE x 8
HW-S_M3x20_socket_ENVELOPE x 4
HW-W_M3_washer_0p5_ENVELOPE x 36
HW-N_M3_nyloc_ENVELOPE x 14
HW-S_M3x16_socket_ENVELOPE x 4
HW-S_M4x35_socket_ENVELOPE x 2
HW-W_M4_washer_0p5_ENVELOPE x 4
HW-N_M4_nyloc_ENVELOPE x 2
HW-S_M3x50_socket_ENVELOPE x 4
HW-S_M2x14_socket_ENVELOPE x 6
HW-S_M3x12_socket_ENVELOPE x 8
HW-S_M2x10_LOW_HEAD_D4_H1p1_ENVELOPE x 4
HW-S_M2x20_socket_ENVELOPE
HW-S_M3x30_socket_ENVELOPE x 2

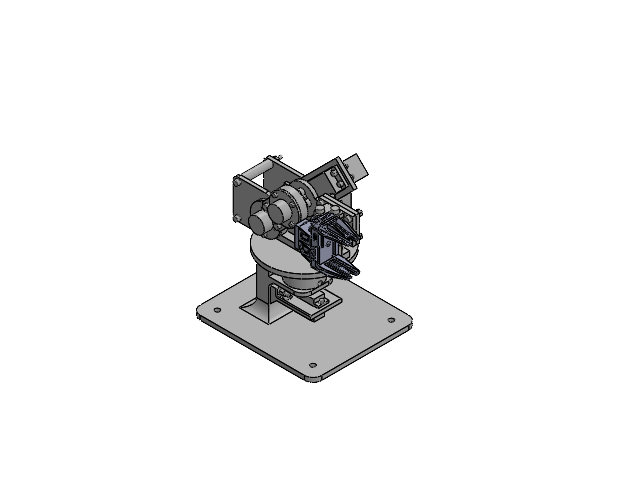
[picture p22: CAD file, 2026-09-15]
cad/arm-v4/development-debug/D_before_equation_repair.SLDASM
ARM-001_Base_pedestal
ARM-202_Yaw_platform
ARM-003_Yaw_D_drive_collar
HW-003_SG90_NOMINAL_VERIFY
HW-001_608ZZ_22x8x7_ENVELOPE x 4
HW-004_MG996R_NOMINAL_VERIFY x 2
ARM-201_Upper_link_dual_MG996R
ARM-204_Modular_forearm_MG996R
ARM-004_Removable_yaw_servo_mount
ARM-203_Bolted_shoulder_upright
HW-005_SG90_COMPACT_CROSS_REFERENCE
HW-006_MG996_25T_D20_PCD14_HORN x 2
ARM-112_SG90_horn_capture_cap
ARM-105_Shoulder_bearing_cheek
ARM-109_Bearing_and_dowel_keeper x 2
HW-002_Dowel_6p35x25p4 x 2
ARM-107_Dowel_to_608_adapter x 4
ARM-108_M3_standoff_32mm x 4
ARM-104_Elbow_bearing_cheek
ARM-205_Parallel_gripper_fork_adapter
HW-203_Pololu3551_jaw x 2
HW-202_Pololu3551_body
ARM-206_Gripper_lug_crush_spacer_13mm x 2
HW-S_M2x10_socket_ENVELOPE x 2
HW-W_M2_washer_0p5_ENVELOPE x 22
HW-N_M2_hex_ENVELOPE x 13
HW-S_M2.5x14_socket_ENVELOPE x 8
HW-W_M2.5_washer_0p5_ENVELOPE x 16
HW-N_M2.5_nyloc_ENVELOPE x 8
HW-S_M3x14_socket_ENVELOPE x 8
HW-W_M3_washer_0p5_ENVELOPE x 36
HW-N_M3_nyloc_ENVELOPE x 14
HW-S_M4x35_socket_ENVELOPE x 2
HW-W_M4_washer_0p5_ENVELOPE x 4
HW-N_M4_nyloc_ENVELOPE x 2
HW-S_M3x50_socket_ENVELOPE x 4
HW-S_M2x14_socket_ENVELOPE x 6
HW-S_M3x12_socket_ENVELOPE x 8
HW-S_M2x10_LOW_HEAD_D4_H1p1_ENVELOPE x 4
HW-S_M2x20_socket_ENVELOPE
HW-S_M3x30_socket_ENVELOPE x 2

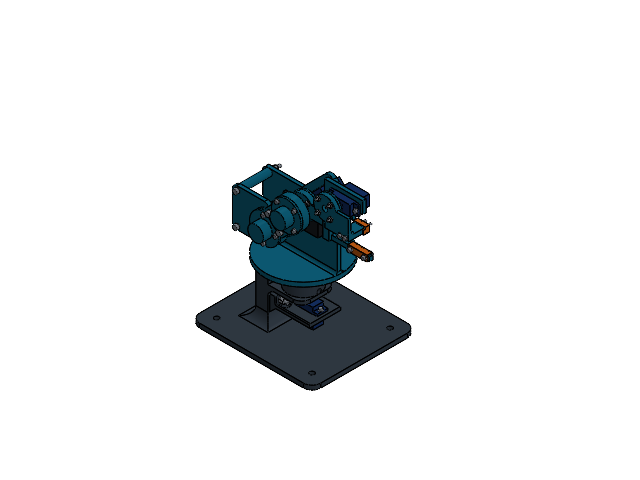
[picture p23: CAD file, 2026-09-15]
cad/arm-v4/development-debug/USER-C_20260912_original_references.SLDASM
ARM-001_Base_pedestal
ARM-002_Yaw_platform_and_shoulder_mount
ARM-003_Yaw_D_drive_collar
HW-003_SG90_NOMINAL_VERIFY x 3
HW-001_608ZZ_22x8x7_ENVELOPE x 4
HW-004_MG996R_NOMINAL_VERIFY
ARM-101_Upper_link_60mm_MG996_SG90
ARM-102_Forearm_and_fixed_jaw
ARM-103_Grip_moving_finger
ARM-004_Removable_yaw_servo_mount
ARM-110_Fixed_jaw_TPU_sock
ARM-111_Moving_jaw_TPU_sock
HW-005_SG90_COMPACT_CROSS_REFERENCE x 3
HW-006_MG996_25T_D20_PCD14_HORN
ARM-112_SG90_horn_capture_cap x 3
ARM-105_Shoulder_bearing_cheek
ARM-109_Bearing_and_dowel_keeper x 2
HW-002_Dowel_6p35x25p4 x 2
ARM-107_Dowel_to_608_adapter x 4
ARM-108_M3_standoff_32mm x 2
ARM-104_Elbow_bearing_cheek
ARM-106_M3_standoff_28p6mm x 2
HW-S_M2x10_socket_ENVELOPE x 8
HW-W_M2_washer_0p5_ENVELOPE x 46
HW-N_M2_hex_ENVELOPE x 29
HW-S_M2.5x14_socket_ENVELOPE x 4
HW-W_M2.5_washer_0p5_ENVELOPE x 8
HW-N_M2.5_nyloc_ENVELOPE x 4
HW-S_M3x50_socket_ENVELOPE x 2
HW-W_M3_washer_0p5_ENVELOPE x 16
HW-N_M3_nyloc_ENVELOPE x 6
HW-S_M3x45_socket_ENVELOPE x 2
HW-S_M2x14_socket_ENVELOPE x 6
HW-S_M3x12_socket_ENVELOPE x 4
HW-S_M2x10_LOW_HEAD_D4_H1p1_ENVELOPE x 12
HW-S_M2x20_socket_ENVELOPE
HW-S_M3x30_socket_ENVELOPE x 2
HW-S_M2x30_socket_ENVELOPE x 2

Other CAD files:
cad/arm-v4/hardware-reference/HW-201_Pololu3551_SUPPLIER.SLDASM
cad/arm-v4/hardware-reference/HW-201a_Pololu3551_import.SLDASM
cad/arm-v4/development-debug/before-sketch-constraints-20260928-185518/ARM-003_Yaw_D_drive_collar.SLDPRT
cad/arm-v4/fabrication-trial/fit-coupon/FIT-003_MG996R_spline_socket_trial.step
cad/_sw_agent_test/agent_desk_arm.SLDPRT
cad/_sw_agent_test/agent_desk_arm.STL
cad/_sw_agent_test/agent_gauge_25x20x10.SLDPRT
cad/_sw_agent_test/agent_gauge_25x20x10.STL
cad/_sw_agent_test/agent_gauge_25x20x10.step
cad/_sw_agent_test/arm_motion/01_base.SLDPRT
cad/_sw_agent_test/arm_motion/02_shoulder.SLDPRT
cad/_sw_agent_test/arm_motion/04_forearm.SLDPRT
cad/arm-v1/ARM-A_Articulated_prototype_DEVELOPMENT.SLDASM
cad/arm-v1/development-debug/20260907-155753/Part1_startup-debug.SLDPRT
cad/arm-v1/development-debug/20260907-155753/Part2_startup-debug.SLDPRT
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

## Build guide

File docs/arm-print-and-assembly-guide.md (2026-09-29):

# Arm D — printing, assembly and commissioning

Open `cad/arm-v4/ARM-D_Modular_parallel_gripper_DEVELOPMENT.SLDASM`. This is the serviceable development revision, updated 2026-09-28 to the owned servo files `MG996R_servo.SLDPRT` (×2) and `SERVO_SG90.SLDPRT`. Owned motors: **two MG996Rs**, driving the shoulder and elbow, and **four SG90s**. One SG90 drives yaw; the other three are unused spares, useful for FIT-004 trials. The gripper's FS90-FB comes with the Pololu kit. It is **not a print release and is not physically qualified**. User revision C and `cad/arm-v3` are preserved.

## What changed in the owned-servo update

- **MG996R mounts (ARM-203 shoulder, ARM-201 elbow).**
  - Body windows are 41.7 × 21.0 mm. That is the file's widest case section (40.7 × 20.0 mm) plus 0.5 mm per side.
  - Ear holes are Ø3.4 on the measured 48.30 × 10.00 mm pattern, for M3 × 14 screws with two washers and a nyloc each. These replace the nominal holes and the M2.5 hardware.
- **ARM-207 printed spline hub (×2) replaces the metal horn.** The files contain no horn, so each hub fits the 25-tooth spline directly:
  - Ø5.80 mm press socket on the Ø5.997 mm spline, 3.0 mm engagement.
  - The underside sits 0.5 mm above the output ring. The 1.0 mm floor seats on the spline top and is clamped by an M3 × 8 low-head centre screw.
  - Four M3 × 12 screws on an 18 mm circle go into captured nuts.
  - The link rear faces stay 16.5 mm above the ear underside, so dowels, sleeves, cheeks, standoffs and M3 × 50 stacks are unchanged.
- **ARM-201 and ARM-204.** The link bolt circle moves from PCD14 to PCD18, with new raised washer seats. The metal-horn holes are suppressed.
- **SG90 yaw.**
  - ARM-004 ear holes move to the measured 27.8 mm pitch (−8.4 / +19.4 mm from the output axis).
  - ARM-003 loses its horn pocket and gains a Ø12 boss with a Ø4.85 × 2.5 mm press socket, 0.5 mm above the gear cover. Its 1.2 mm floor seats on the spline top, retained by the servo's own M2 horn screw.
  - The ARM-003 crossbolt hole opens to Ø2.8, giving ±0.4 mm axial float. The arm's weight then stays on the 608 bearings instead of the SG90 output.
  - ARM-112 and its low-profile screws are no longer needed.
- **Pickup trial pose** is now shoulder −15° / elbow −75° (was −15° / −80°). The forearm is vertical, so the jaws close coaxially with the 608ZZ pin.

## Owned-servo geometry used (native measurement, not calipers)

- **MG996R** (native part; case and spline bodies; no horn, no cable, no material):
  - Ear underside is the mounting datum. Ear thickness in the file: 2.40 mm at the output end, 1.754 mm at the far end.
  - Ø4.0 open-slot holes at −14.15 / +34.15 × ±5.00 mm from the output axis.
  - Case 40.0–40.7 × 20.0 mm, 27.99 mm below the ear underside.
  - Output ring (Ø10.8) top is 12.0 mm above the ears. The 25-tooth spline (tip Ø5.997, root ≈Ø5.42) reaches 15.5 mm, 3.5 mm exposed.
  - M3 centre thread, 8.19 mm deep.
- **SG90** (STEP import; case, spline and three cable stubs; no horn, no material):
  - Ears 2.4 mm thick with Ø2.5 open-slot holes at −8.4 / +19.4 mm.
  - Case 12.0 × 23.0 mm.
  - Gear cover (Ø12 plus a Ø5 lobe) top is 11.4 mm above the ear underside (9.0 above the ear top).
  - Plain Ø5.0 spline with 40 shallow grooves and no tooth form, 3.0 mm exposed, top 14.4 mm above the ear underside.
  - Ø1.0 plain centre hole.
  - Three Ø1.2 cable stubs exit the output end 12.7 mm below the ears.

## Native controls and verified state

Six named configurations cover home, 22 mm grip, pickup and three transfer poses. `07_Free_motion_CHECK_COLLISIONS` releases the three arm angles with provisional limits; it does not certify every combined pose.

- Physical yaw: −60 to +60°. D1@J1_Yaw_command = 90° + yaw.
- Shoulder: −15 to +80°. D1@J2_Shoulder_command = 90° + shoulder.
- Elbow: −100 to −5°. D1@J3_Elbow_command = −elbow.
- Edit the **Gripper_opening** global variable, provisionally **2–32 mm**. It drives both jaws symmetrically.

**Verified 2026-09-28 on the reopened assembly:**

- **References:** 191 active components, all resolving inside `arm-v4` across 38 unique parts. 75 superseded components and their mates suppressed in every configuration.
- **Solver and features:** zero mate errors, zero part feature errors. The six saved poses match the kinematic model within 1.1e-15 of the stored transforms.
- **Revision C:** 38 files unchanged by hash.
- **Interference:** native solid interference was checked in all six saved configurations, plus 11 review poses and 19 transfer/lift samples. There are **0 unexpected overlaps**.
  - Each state shows the same 93 designed engagements, reported separately: the hub and collar press fits on the modeled splines, and the centre screws in the M3 thread and the SG90's Ø1.0 hole.
  - Full 0 mm closure shows 2 small supplier-model overlaps, outside the 2–32 mm working range.
- **Limits:** these are discrete samples, not a swept proof. Cables, external fixtures and a real payload are not covered.

## Material and printing

Use **PETG for the first structural set**. Follow the actual filament and printer profile, not universal temperature settings. [Prusa PETG guidance](https://help.prusa3d.com/article/petg_2059)

Starting process proposal: 0.4 mm nozzle, 0.20 mm layers, 5–6 walls, 5 top/bottom layers, 35–50% infill on broad structures, locally solid bearing seats and bolt regions. These are trial settings, not a validated strength specification.

- **ARM-207 hubs and ARM-003 collar:** print **solid**, socket face down on the bed so the socket is in the most accurate XY plane. Use 0.12–0.16 mm layers if the printer allows. FDM will not reproduce spline teeth; the socket is a press/broach fit whose bore is selected with the coupons.
- **Base ARM-001:** foot flat on the bed. Support the elevated bridge as needed; keep support scars out of bearing seats.
- **Platform ARM-202:** broad upper face on the bed, spindle up.
- **Upright ARM-203:** foot on the bed, supports for the servo-window roof as needed.
- **Upper ARM-201 and forearm ARM-204:** rear face on the bed (still flat; the hub is a separate part), hubs up.
- **Fork ARM-205:** base flat. Clean the two 4.3 mm holes.
- **Cheeks, keepers, cassette:** broad mounting faces on the bed. Print sleeves and standoffs with bores vertical.

Use only `cad/arm-v4/fabrication-trial/manifest.json` and its 18 listed files (refreshed 2026-09-28 for the changed parts). Never print HW reference parts or anything under `superseded-2026-09-28`.

## Fit trials first

1. **FIT-003 (MG996R).** Sockets Ø5.70 / 5.80 / 5.90 / 6.00, 3.0 mm deep, from the orientation mark. Press each onto a centred owned MG996R, fit the M3 centre screw, then check:
   - the coupon floor seats on the spline top, leaving about 0.5 mm above the output ring;
   - there is no cracking;
   - it doesn't slip under a gentle hand torque well above the 0.24 N·m shoulder design torque.
2. **FIT-004 (SG90).** Sockets Ø4.65 / 4.75 / 4.85 / 4.95, 2.5 mm deep, tested the same way on a spare SG90.
3. **Apply the result.** Set the selected bores in ARM-207 (modeled Ø5.80) and ARM-003 (modeled Ø4.85), then re-run the CAD verification.
4. **FIT-001:** bearing seat and dowel fits, as before.

## Assembly, tool to base

1. **Purchased gripper:** assemble the kit using the [supplier's guide](https://www.pololu.com/docs/0J76). Verify both paddles slide freely.
2. **Fork and crush spacers:** fit the two ARM-206 spacers between the plastic ears. Fit two M4 × 35 screws, two washers each and M4 nylocs. Tighten only enough to remove play, then confirm jaw travel.
3. **Forearm tool deck:** fasten ARM-205 to ARM-204 with four M3 × 14, two washers each and nylocs, before fitting the forearm to the elbow.
4. **Elbow servo:**
   - Drop the elbow MG996R through the ARM-201 window. Fasten each ear with M3 × 14, a washer on the ear, a washer and nyloc under the link.
   - Centre the servo electrically.
   - Seat four M3 hex nuts in an ARM-207 hub, press the hub onto the spline until its floor bottoms on the spline top, and fit the M3 × 8 low-head centre screw.
   - Fit ARM-204 onto the hub with four M3 × 12 and washers into the captured nuts.
5. **Elbow passive support (unchanged):**
   - Slide the link-side ARM-107 sleeve into the forearm bore over the centre-screw head (the head sits inside the sleeve with 1.0 mm to the dowel end).
   - Install the dowel and the second sleeve.
   - Fit the 608 in ARM-104 with its ARM-109 keeper and three M2 × 14 stacks.
   - Mount the cheek on two 32 mm ARM-108 standoffs with M3 × 50 stacks.
6. **Shoulder:** repeat the MG996R, hub, centre-screw and M3 × 12 sequence at ARM-203 and ARM-201. Then fit the shoulder dowel, sleeves, 608, ARM-105 cheek, ARM-109 keeper, standoffs and M3 × 50 stacks.
7. **Upright to platform:** nylocs in ARM-202's underside recesses, then four M3 × 14 with washers.
8. **Yaw:**
   - Fit two 608s in ARM-001.
   - Fasten the SG90 in ARM-004 with two M2 × 10, no washers, and M2 nuts under the shelf, flats toward the case.
   - Press ARM-003 onto the spline until its floor seats, then fit the SG90's own horn screw through the collar floor.
   - Mount the cassette with two M3 × 30 stacks.
   - Lower the platform spindle through the bearings into the collar D-key and fit the M2 × 20 crossbolt stack.
   - Check by hand that the spindle shoulder rests on the upper 608 inner race: the Ø2.8 collar hole should let the bolt float. Also check about 0.4 mm between the horn-screw head and the spindle end.
9. **Bench and cables:**
   - Clamp the 140 × 120 mm base.
   - The SG90 cable leaves the output end below the shelf; the MG996R cable is not in its file.
   - The shoulder, elbow and gripper cables must cross the ±60° yaw joint with a service loop.
   - Route strain-relieved loops outside every sweep and check screwdriver access. CAD does not model flexible wires.

## Pickup, lift and transfer

At `03_Pickup_trial` the jaws hang vertically. The jaw tips are the gripper's lowest point, about 16.5 mm above the bench plane, beside the base (assembly z ≈ 75 mm). The pickup fixture must present the 608ZZ on its pin at that height.

For the first 10 mm off the pin, command a **Cartesian vertical lift** (planar inverse kinematics at the 90 mm grip point), not a joint-space move. The CAD samples show the forearm rotating only 1.14° over that lift with no horizontal drift. The joint angles are in `transfer-path-inspection.json`. After the bearing clears the pin, joint-space motion to the transfer pose was sampled clear.

## Loads, power and proof before repeated use

The solid-PETG/native-volume estimate is **639.3 g** for modeled hardware and prints, excluding supply and controller. The servo files carry no material, so reference masses are used: MG996R 55 g, SG90 9 g.

With a 20 g payload at 90 mm, cable allowances and a 1.25 load multiplier, the design torques are:

- **elbow: 0.077 N·m**, margin **3.58**;
- **shoulder: 0.243 N·m**, margin **1.14**.

Both are against an assumed 0.277 N·m operating budget (one-third reference stall, further reduced 10%). These are sizing assumptions, not measured servo ratings. The shoulder governs; do not add distal mass, payload or duty from these numbers alone.

Power servos from the separate regulated supply and rated distribution, sharing signal ground with the Mega. Keep motor current off the Mega regulator and breadboard rails. Use an accessible DC disconnect and support the arm when power is removed.

Calibrate one servo at a time with the arm supported, then try slow unloaded motion. The gripper's pulse range is unusually wide; find its usable endpoints gradually. Feedback indicates position, not grip force. Test retention over a catch surface at 5, 10 and 20 g. Record current, voltage, case temperature, drift, slips and hub or fastener movement.

For the next gate, run 50 pick/place cycles with at least 49 successes. Record placement spread and failures, inspect the hubs, sockets and printed joints, and repeat after a sustained-duty trial. No fit, cycle, thermal, grip-force or repeatability performance has been measured yet.

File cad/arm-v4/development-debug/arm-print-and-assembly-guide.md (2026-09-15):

# Articulated arm — print and assembly guide

Revision C development, 2026-09-08. Arm 3 is now assembled in SolidWorks: 190 components, 43 fastener stacks, and 24 printed instances across 16 part types. Nine review poses and twelve transfer-path samples passed native solid-interference checks. These discrete checks do not prove continuous swept clearance. No physical arm has been tested. Hardware quantities and planning costs are in [arm-bom.md](arm-bom.md).

## Fabrication hold: match the actual horns

Print the fit coupons first. The C shoulder interface now targets a 20 mm disc with four M3 tapped holes on a **14 mm bolt circle**, matching this [commercial MG996R-compatible 25T horn drawing](https://robu-prod-media.s3.ap-south-1.amazonaws.com/uploads/2017/06/watermarked_sku-30643.pdf). The upper link includes raised washer seats and uses four M3 screws threaded into the metal horn. Confirm the selected horn's dimensions, spline compatibility and screw engagement before ordering its attachment hardware.

Luis confirmed the small equal-arm cross horn. Arm 3 captures that unmodified horn in a shaped pocket with a removable rear cap; four M2 bolts pass **between** its arms. The stock spline and blade edges transmit torque. The tiny stock pilot holes are not enlarged. The [supplier drawing, pages 4–5](https://www.auselectronicsdirect.com.au/assets/brochures/TA0132.pdf) informs the reference envelope, including the raised gearbox cover and 4 mm overall horn thickness. The assumed seated horn-front height is 13.2 mm above the mounting-ear top; this must be checked on the actual motor. The modeled minimum cap-screw/cover axial gap is only 0.2 mm, so measure it across travel and adjust before use. Imported COTS models can replace these simple references.

Try the three FIT-002 pockets (0.05, 0.10 and 0.15 mm nominal flank clearance per side) with one ARM-112 cap. Choose a snug sliding fit with no forced seating or perceptible rocking. The pocket is 1.65 mm deep for a nominal 1.5 mm blade; a measured thin PET shim can remove axial rattle. Tighten against the printed cap seats, never use bolt force to pull a partly seated horn onto its spline. Keep the original center screw accessible and install the passive dowel afterward.

## Material choice

Use **PETG for working housings, bearing retainers, servo mounts and structural links**, subject to makerspace support. Its toughness and layer adhesion suit mechanical mounts. **PLA is suitable for initial fit coupons and low-duty indoor geometry trials**; it is easier to print but more brittle and less heat tolerant. Both materials can creep under sustained clamp loads: use washers and positive shaft retainers. Material characteristics: [Prusa PETG guide](https://help.prusa3d.com/article/petg_2059) and [PLA guide](https://help.prusa3d.com/article/pla_2062).

Use captured soft rubber or **TPU pads** at the gripper contacts. Pad friction remains a measured input, especially with oily bearings. Do not assume carbon-filled filament or nylon fixes weak geometry: they require controlled printing, drying and fit calibration. Start with an ordinary material supported by the shop and change it only in response to a measured problem.

## Proposed starting print settings

These are engineering starting points, not validated strength data or universal printer profiles.

- 0.4 mm nozzle; 0.20 mm layers; manufacturer-approved filament temperatures and bed preparation.
- Five perimeters, five to six top/bottom layers, and 35–40% infill on structural parts. Inspect sliced thin sections; they may be almost all perimeters.
- Print links flat with their long axes in the bed plane. Keep primary bending loads along continuous extrusion paths, not peeling across layer boundaries.
- Prefer vertical hole axes for bearing and pin seats. Avoid support scars on fits; split a housing and add a bolted keeper if needed.
- Add local solid regions around holes if needed. More infill does not replace edge distance, fillets, washers or a sound load path.
- Weigh the finished parts and update the torque calculation before fitting the payload. CAD solid volume is not the slicer's printed mass.

## Measure and print coupons first

Measure two SG90 bodies, mounting tabs, shaft offsets, stock horns and fasteners. Keep the purchased horn/spline interfaces; a guessed printed spline is unacceptable. The MG996R shoulder is additional hardware, with a reference envelope pending confirmation of the actual purchased unit.

The BOM gives 608ZZ bearings at 22 mm OD × 8 mm ID × 7 mm wide and dowels at 6.35 × 25.4 mm. A bare dowel in that bearing has **0.825 mm radial clearance**. Use an engineered sleeve or a smooth 8 mm shaft at working bearing pivots. Do not run a bearing inner race directly on screw threads.

Print trials for bearing seats at 22.0, 22.1, 22.2 and 22.3 mm and dowel fits at 6.35, 6.45, 6.55 and 6.65 mm. This is an experimental sweep, not a tolerance class. Measure cooled prints and choose the fit from insertion and rotation behavior. Seat the outer race without crushing the housing, and retain it with a removable keeper. During installation, apply force only to the race being seated. A washer must not bridge and clamp both races together.

Print a servo mount and captured-horn trial next. Verify screw access, horn sweep and cable clearance before printing complete links. The SG90 case sits through the mounting window, with its ears on the mounting shelf and two M2 screws retaining it. The revised elbow spacing and taller moving finger provide room for the raised servo cover.

## Hardware and power

The project lists purchased SG90s, 608ZZ bearings and 6.35 × 25.4 mm dowels, plus an ELEGOO Mega R3, breadboard and jumpers. The arm assigns three SG90s to yaw, elbow and grip. The proposed shoulder uses **one MG996R positional servo**, additional hardware. Do not buy a continuous-rotation variant.

The [TowerPro SG90 reference](https://towerpro.com.tw/product/sg90-7/) gives 1.8 kgf·cm stall torque at 4.8 V for its digital variant and recommends external power. That is about 0.177 N·m at stall, not a continuous-duty rating for the user's actual motors. [TowerPro's MG996R reference](https://towerpro.com.tw/product/mg996r/) lists 9.4 kgf·cm at 4.8 V and nominal dimensions 40.7 × 19.7 × 42.9 mm. Both references require checking against the actual units.

The calculation budgets one-third of reference stall torque, applies a 1.25 load multiplier, and reserves 10% at the direct shoulder connection. These are design assumptions, not measured ratings. The earlier 3:1 SG90 shoulder candidate was abandoned because it restricted shoulder travel to about 50 degrees and had little estimated load margin.

Additional hardware will include machine screws/nuts/washers for removable housings, actual horn-compatible screws, positive bearing/shaft retainers, soft pads and a catch tray. Exact screw lengths and quantities must come from the verified assembly stack. Keep each original servo center screw with its horn; verify engagement and avoid bottoming it out.

Use a regulated external servo supply and proper power distribution. Select current capacity from simultaneous-load measurements and actual servo specifications. Do not power the loaded arm through the Mega USB supply, board regulator or breadboard power rails. Connect controller and servo grounds; size the wiring for the intended current and provide an accessible power disconnect.

## Intended assembly and test sequence

1. Inspect and deburr prints. Fit bearings and verify each axis moves freely before adding servos. Install positive axial retainers.
2. Assemble the base; clamp it to the bench for first tests. Check the support polygon and overturning moment before relying on an unclamped base.
3. Center each unloaded servo at a verified electrical position before fitting its stock horn. Keep center-screw access and allow small mounting adjustments.
4. Assemble shoulder, upper link and elbow. Bearings/bushings should carry bending loads; the servo should primarily transmit torque. Check all clamping and retention stacks.
5. Add forearm and gripper. Confirm pad contact, bearing clearance and full release. Servo stall must not be the normal closing stop.
6. Route service loops with strain relief. Cables must never become motion stops.
7. Support the arm and bring up one unloaded axis at a time. Establish actual travel limits before fitting a payload. Software limits stop short of physical and cable limits.
8. Check the full swept volume and pickup/placement poses. This arm has no independent wrist orientation: reachable position alone is insufficient.
9. Increase load in steps, such as 5, 10 and 20 g. Record voltage/current, sag, backlash and temperature over the proposed duty cycle. Investigate binding or sustained buzzing.
10. Run 50-cycle retention and repeatability trials only after low-speed checks pass. Record measured results. On power loss the arm may back-drive or drop the payload; support it during assembly and keep the work above a catch tray.

## Files and memory

Current work lives in `cad/arm-v3`; Arm 2 remains preserved in `cad/arm-v2`. Open `ARM-C_Articulated_prototype_DEVELOPMENT.SLDASM`. Native SLDPRT/SLDASM features are the editing masters; STEP is for exchange and STL for slicing. Its 16 active printed part types have 115 fully constrained sketches, with unchanged-solid checks. Consult the C verification reports for saved-assembly checks. The JSON sizing parameters are a calculation record; they do not drive every dimension in the geometry generator. Preserve a revision before regenerating anything manually edited. After replacing a native part, refresh mates referencing its old faces; a cached position is not proof that the references still resolve.

Build one part at a time, save it, then close its document. Purchased parts use simplified envelopes, without balls, threads or motor internals. Keep only the assembly and the part being edited open. Avoid FEA and render jobs during CAD construction on this 16 GB computer.

## Review the articulation in SolidWorks

Use the ConfigurationManager to select `01_Home`, `02_Grip_open`, `03_Pickup_trial`, `04_Transfer`, `05_Transfer_left` or `06_Transfer_right`. These store independent native mate dimensions. The first six configurations hold a pose; edit their angle mates to move them.

`07_Free_motion_CHECK_COLLISIONS` suppresses the four fixed angle commands and enables native limit mates for dragging. Provisional bounds are yaw -60 to +60, shoulder -30 to +80, elbow -100 to -5 and grip 0 to 25 degrees. The native limits have been read back and their mate features report no errors. These bounds do not guarantee that every combination clears the rest of the arm; use collision detection while exploring and return to a named checked pose for review. They are not the actual servos' calibrated electrical limits.

In the Mates folder, the four command dimensions are `D1@J1_Yaw_command`, `D1@J2_Shoulder_command`, `D1@J3_Elbow_command` and `D1@J4_Grip_command`. Their CAD values in degrees are respectively **90 + yaw**, **90 + shoulder elevation**, **minus elbow relative angle**, and **90 + grip opening**. Home is 90, 135, 45 and 90 degrees. These are CAD angles, not calibrated servo commands. Change dimensions for the current configuration and rebuild; keep backups before editing geometry.

The revised pickup uses yaw 0, shoulder -30, elbow -60 and grip 10 degrees. The earlier shoulder -40/elbow -50 pose hit the yaw platform and is rejected. Transfer uses shoulder 20 and elbow -20; yaw samples cover -60 to +60 degrees. Grip 25 degrees clears the corrected pad relief. Arbitrary combinations, cables, tools, the payload and external fixtures require their own checks.

## Current first-principles estimates

`cad/arm-v3/cad-load-and-bom-report.json` uses native volumes, 100% solid PETG mass, nominal purchased masses and explicit cable/payload allowances. Total modeled mass is about **526 g**, before unmodeled wiring and the payload. This overstates the printed infill mass but does not establish the true servo or bearing mass.

The mass calculation is external to SolidWorks' default material assignments. Use this report for the stated assumptions; do not treat an unassigned native material's mass-property result as the arm's measured mass.

With a 20 g payload, the calculated elbow design torque is **0.0427 N·m** against an assumed **0.0588 N·m** budget; the shoulder is **0.1336 N·m** against **0.2765 N·m**. Margins are approximately **1.38** and **2.07**. These include the 1.25 load multiplier and conservative lever bounds; the budgets are assumptions derived from reference stall torque, not continuous ratings. Retest with weighed parts and actual servos.

For a 22 mm circular object centered at forearm coordinates (69, 1, 3) mm, ideal rigid pad contact occurs near **7.83 degrees grip opening**, inside the usable pad face. With assumed friction coefficient 0.3, a two-times-weight allowance and allowance for the jaw angle, the estimate is **0.85 N normal force per contact** and **0.0168 N·m grip torque**. Pad compression, friction, contact width and retention remain physical tests. The 10-degree CAD transfer pose is a clearance demonstration, not a validated holding command.

## Part orientation and fabrication files

Use the curated `cad/arm-v3/fabrication-trial` files and manifest: 16 arm part types and four coupon types have been exported and checked for watertightness, positive volume and agreement with native volume. `fit-coupon` is the first print; add one ARM-112 cap from `candidate-parts` for the horn trial. The full candidate set remains subject to the horn and hardware-fit hold above. Individual exports use millimetres and fine STL resolution. Do not batch-print the raw `parts` directory, which preserves superseded candidates alongside the native masters.

- **ARM-001 base:** bench face on the bed; support the elevated bearing bridge. Keep support contact out of the finished bearing seats where possible.
- **ARM-002 yaw upright:** its spindle, platform and upright prevent a simple support-free orientation. Review a side-on orientation with the makerspace and use removable supports beneath the platform/shaft. Verify the spindle and bearing-fit surfaces after support removal; this is a candidate that may benefit from splitting into bolted parts after the first fit trial.
- **ARM-003 collar and ARM-004 cassette:** place a broad flat face down. Keep the collar axis vertical if possible; use local support only where the cassette geometry requires it.
- **ARM-101 upper:** broad rear web face on the bed, bearing axis vertical.
- **ARM-102 forearm:** keep its web parallel to the bed. The horn-pocket boss extends 1.65 mm behind the web, so this is not a single flat-bottom print. Plan removable support beneath the raised web and gripper mount, with the horn pocket kept clear of support scars. Review this orientation in the slicer before committing the full link.
- **ARM-103 moving finger:** horn attachment plate on the bed, with the hanging finger extending upward. This avoids bridging the full horn plate above a narrow fingertip.
- **ARM-104/105 bearing cheeks:** place the inner lip face down, open bearing pocket upward. Confirm the slicer preserves the retaining lip.
- **ARM-106/108 standoffs and ARM-107 sleeves:** axes vertical; use enough perimeters to make the thin sleeve wall continuous. Print extra sleeves for fit selection.
- **ARM-109 keepers:** cup end on the bed, open cavity upward, with supports under the outward flange if required. Inspect and deburr the internal pin clearance.
- **ARM-110 fixed TPU sock:** the pocket runs along the finger; orient its open passage vertically where adhesion permits, with a brim. Avoid trapped support in the sleeve.
- **ARM-111 moving TPU sock:** closed bottom on the bed, open pocket upward.
- **ARM-112 horn caps:** plain flat face on the bed, head counterbores upward; keep the thin remaining floor clean. Three caps are required. Low-profile screw heads must match the modeled maximum 4 mm diameter × 1.1 mm height.
- **FIT-002 horn trials:** broad load-plate face down, shaped pocket upward. Print one cap alongside the three trial clearances.
- **FIT-001 coupon:** broad face on the bed, hole axes vertical. Bearing holes increase left to right from 22.0 to 22.3 mm; dowel holes increase from 6.35 to 6.65 mm. Mark the underside before removing it from the bed so orientation is unambiguous.

## Part-by-part walkthrough: gripper down to the bench

**Moving pad — ARM-111.** This is the soft TPU contact sleeve at the moving fingertip. Slide it over the bottom of ARM-103. Two M2 × 30 screws pass through the taller C finger and pad; use a washer at each end and an M2 nut. Tighten only enough to retain the sleeve. Excess preload crushes the TPU and can split printed walls.

**Moving finger — ARM-103.** Capture the gripper's stock cross horn between its shaped pocket and one ARM-112 cap. Use four M2 × 10 low-profile screws, four front washers and four front nuts. Heads face the servo and sit in the cap recesses; omit rear washers. The central opening gives access to the original horn center screw. Closing rotates this finger; the jaws do not remain parallel. Calibrate closing at actual object contact and do not use continuous servo stall to hold the bearing.

**Fixed pad — ARM-110.** This TPU sleeve wraps the fixed finger built into the forearm. Slide it along the bar to align the two holes. Two M2 × 10 screws, four washers and two nuts capture it. It can be replaced independently when worn.

**Forearm and fixed jaw — ARM-102.** This PETG part carries the fixed contact, gripper servo and elbow horn connection. Mount the gripper SG90 through the body window with two M2 × 10 ordinary socket screws, four washers and two nuts. At the elbow end, capture its stock horn using one ARM-112 cap, four M2 × 10 low-profile screws, four front washers and four nuts. Secure the original horn center screw before inserting the passive support pin.

**Elbow support pin and sleeves — HW-002 and ARM-107.** One 6.35 × 25.4 mm dowel spans the forearm hub and passive-side bearing. Two printed sleeves adapt the pin to the 8 mm nominal seats, one in the link and one in the bearing. Check fits first; there must be no perceptible radial slop, binding or sleeve migration. The pin is a support axle, not a substitute for the servo horn's torque connection. Its inner end is offset to preserve center-screw clearance; its outer end is enclosed by the keeper.

**Elbow bearing cheek — ARM-104.** This stationary support relative to the upper link carries one 608ZZ bearing. Insert the bearing from the open outer side until it meets the inner retaining lip. Two C ARM-106 standoffs, each 28.6 mm long, connect the cheek to the upper link using two M3 × 45 screws, four small-series M3 washers and two M3 nylon-insert nuts. These screws clamp the printed standoffs, not the rotating link. Do not use the preserved 24 mm B standoffs with this revision.

**Elbow keeper — ARM-109.** Three M2 × 14 screws, six washers and three nuts attach this cap to ARM-104. Its thin outer contact rim seats against the housing while leaving nominal axial clearance at the bearing face. The central cup encloses the pin end. Check that the pin and inner race rotate freely after tightening; neither should rub the cap.

**Upper link — ARM-101.** This PETG link places the elbow axis 60 mm from the shoulder. It holds the elbow SG90 with two M2 × 10 screws, four washers and two nuts. Four M3 × 12 screws with four small-series washers connect its shoulder flange to the metal horn's tapped holes; no separate horn nuts are used. Raised washer seats clear the central sleeve. Confirm screw engagement and case clearance on the actual horn. Install the original shoulder center screw while access remains open, then fit the support pin.

**Shoulder passive support — ARM-105, ARM-108, ARM-107, HW-002 and ARM-109.** This repeats the elbow's bearing-supported arrangement at the stronger joint. Use one 608ZZ, one dowel, two adapter sleeves and two 32 mm ARM-108 standoffs. Two M3 × 50 screws, four small-series M3 washers and two M3 nylon-insert nuts clamp the standoffs between the rotating base's upright and the cheek. Three M2 × 14 screws, six washers and three nuts secure the outer keeper. The cheek stays with the yaw upright while the upper link rotates.

**Shoulder servo — MG996R reference.** Its case fits through the upright window in ARM-002. Four M2.5 × 14 screws, eight small-series M2.5 washers and four M2.5 nylon-insert nuts secure its ears. These smaller fasteners leave clearance beside the servo case; do not substitute larger nuts simply because they fit through the printed hole. The horn transmits torque, while the opposite dowel/bearing support reduces cantilever loading on the servo output.

**Yaw platform and upright — ARM-002.** This part rotates the shoulder and the whole arm about the vertical base axis. Its hollow spindle runs through the two base bearings. The spindle's D-shaped end engages ARM-003. Preserve the spindle shoulders, flat and crosshole when editing: they define the support and retention stack.

**Yaw drive collar — ARM-003.** One ARM-112 cap and four M2 × 10 low-profile screws capture the stock yaw cross horn; use four front washers and nuts. Assemble this connection and its original center screw before inserting the cassette. A single M2 × 20 crossbolt, two washers and one nut positively retain the collar and spindle. The recessed flat seats support the crossbolt hardware; the D-shaped interface carries driving torque.

**Removable yaw-servo cassette — ARM-004.** Mount its SG90 with two M2 × 10 screws, four washers and two nuts. Center the servo and fit its stock horn/center screw before closing access. The cassette attaches to the pedestal backbone using two M3 × 30 screws, four small-series M3 washers and two M3 nylon-insert nuts. The side pockets allow nut access. The intended insertion is from the open side below the bearing bridge, then upward into the final position; verify this path with the actual horn and leads before loading the arm.

**Base pedestal — ARM-001.** Two 608ZZ bearings support the yaw spindle above the servo. The spacer shoulder separates them. Fit the bearings, spindle and collar as one retained module; support loose bearings during assembly. The base includes tool access to the crossbolt and four 5.5 mm fixture holes. Clamp or bolt it to a rigid bench board. Choose fixture screw lengths from the actual board thickness rather than the CAD base alone.

## Practical build order

Read the walkthrough from gripper to base to understand the load path, but physically build the base first. Then prepare the three link/horn subassemblies on the bench, fit the shoulder and elbow supports, and add the pads and service loops. Keep each original servo center screw accessible until its horn has been centered and verified. Check free motion after every support or keeper is tightened.

The arm has yaw, shoulder, elbow and grip actuation. It has **no independently controlled wrist orientation**. A pickup fixture and trajectory must accommodate the gripper's changing orientation. The old vertical locating-pin pickup is not automatically compatible with this new articulated architecture.

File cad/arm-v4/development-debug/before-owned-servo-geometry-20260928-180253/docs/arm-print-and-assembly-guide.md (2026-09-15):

# Arm D — printing, assembly and commissioning

Open `cad/arm-v4/ARM-D_Modular_parallel_gripper_DEVELOPMENT.SLDASM`. This is the serviceable development revision, with preserved user C files. It is **not physically qualified for production**. The native model uses a modular parallel gripper, two owned MG996Rs, and separate yaw platform/upright parts.

## What changed and why

- ARM-002's combined spindle/platform/upright becomes **ARM-202 platform** and **ARM-203 upright**. They can be printed and replaced separately. Captured nuts sit 3 mm into the platform so the hardware clears the base during yaw.
- The asymmetric ARM-102/103 finger arrangement becomes a **straight ARM-204 forearm**, **ARM-205 removable fork**, and purchased synchronized parallel jaws. Opposed contact avoids the old finger's sweeping/wedging geometry. The supplier mechanism also removes two custom SG90 horn clamps.
- **ARM-201** uses the second MG996R at the elbow. Both pitch joints now share the same metal-horn interface and 32 mm standoff length. The 60 mm upper-link centers are retained.
- Your saved C fillets/chamfers remain in the derived platform/upright/upper-link histories and copied unchanged components. Old C fingers remain archived; do not print them for D.

## Native controls and verified limits

Use the six named configurations for home, 22 mm grip, pickup and transfer. `07_Free_motion_CHECK_COLLISIONS` releases the three arm angles with provisional limits; it does not certify every combined pose.

- Physical yaw: −60 to +60°. Native D1@J1_Yaw_command = 90° + yaw.
- Shoulder: −15 to +80°. D1@J2_Shoulder_command = 90° + shoulder.
- Elbow: −100 to −5°. D1@J3_Elbow_command = −elbow.
- Edit the native **Gripper_opening** global variable, provisionally **2–32 mm**. It drives both jaw positions symmetrically; do not edit one paddle independently.

Pickup is now shoulder −15° / elbow −80°. The larger elbow case collided with the upright at the old −30° shoulder position. Ten intended poses and twelve lift/yaw samples were checked with independent component-transform comparisons and native solid interference detection. All were clear after the screw/nut corrections. Full closure at 0 mm produced two small supplier-internal overlaps (~0.092 mm³ each); 2 mm and reopening were clear. This is the reason for the provisional minimum. Continuous swept clearance, external fixtures, loose cables and a real payload are not covered by those checks.

## Material and printing

Use **PETG for the first structural set**. It is a practical technical-print material, with good toughness and relatively low warping; bridges and support removal need care. Follow the actual filament/printer profile rather than universal temperature settings. [Prusa PETG guidance](https://help.prusa3d.com/article/petg_2059)

Starting process proposal: 0.4 mm nozzle, 0.20 mm layers, 5–6 walls, 5 top/bottom layers, 35–50% infill on broad structures, and locally solid bearing seats/bolt regions. Small sleeves, horn cap and crush spacers should print solid. These are trial settings, not a validated strength specification. Check slicer mass and load-direction layer bonding. PLA is useful for quick dimensional mockups; avoid treating a PLA mockup as a sustained-load/thermal qualification. TPU/rubber is optional for gripping surfaces, not structural links. ASA/PC/nylon require a suitable printer and new fit/process validation; a more expensive filament does not automatically improve this arm.

- **Base ARM-001:** foot flat on the bed. Support the elevated bridge as needed; keep support scars out of bearing seats.
- **Platform ARM-202:** broad upper face on the bed, spindle pointing upward. The underside nut recesses then open upward. Inspect the D-flat/cross-hole and remaining walls.
- **Upright ARM-203:** foot on the bed, with supports for the servo-window roof as needed. Inspect the rib/foot junction and keep bearing/servo mounting datums clean.
- **Upper ARM-201 and forearm ARM-204:** broad rear face on the bed, hubs upward. This keeps the long link geometry in the layer plane.
- **Fork ARM-205:** base flat. Clean the two horizontal 4.3 mm holes; confirm a sliding M4 fit without forcing the plastic ears.
- **Cheeks/keepers/cassette:** orient their broad mounting faces for stable support. Remove support before trying bearings. Print sleeves and round standoffs with bores vertical.

Use only `cad/arm-v4/fabrication-trial/manifest.json` and its individual candidate/coupon files once that export is complete. The raw parts folder contains preserved superseded parts and development exports. Never print HW reference parts. Print FIT-001 bearing/dowel trials, FIT-002 horn-pocket trials and one ARM-112 cap first. Check the real seated yaw-horn height: the earlier 13.2 mm value is assumed and its minimum modeled cap/cover gap is only 0.2 mm.

## Assembly, tool to base

1. **Purchased gripper:** assemble the kit using the [supplier's Romi-arm guide](https://www.pololu.com/docs/0J76). Verify both paddles slide freely before installing it. Its servo is included; an SG90 substitution is not assumed compatible.
2. **Fork and crush spacers:** insert the two ARM-206 spacers between the paired plastic mounting ears. Place the gripper between ARM-205's outer cheeks. Fit two M4×35 screws, two washers per screw and M4 nylocs through the matching axes. Tighten by hand only enough to remove play; the spacers resist squeezing the ears inward. Verify smooth jaw travel afterward.
3. **Forearm tool deck:** fasten ARM-205 to ARM-204 with four M3×14, two small-series washers each and M3 nylocs. Assemble this module before attaching it to the elbow so the underside nuts are accessible. Longer screws can reach the elbow case.
4. **Elbow drive:** center the actual MG996R electrically, then fit its matching metal horn and original center screw. Bolt the forearm flange to the horn with four M3×12 and small-series washers. The raised seats clear the dowel sleeve. Confirm thread engagement and that protruding screw tips clear the case through travel.
5. **Elbow passive support:** install the dowel and two ARM-107 sleeves. The dowel starts 3 mm into the forearm-side stack and spans the passive support. Fit the 608 bearing in ARM-104, add its ARM-109 keeper using three M2×14 stacks, and mount the cheek on two 32 mm ARM-108 standoffs with M3×50 stacks. The keeper prevents pin escape while preserving the modeled end float; do not preload/bind the bearing. Elbow servo ears use four M2.5×14 stacks in ARM-201.
6. **Shoulder:** repeat the metal-horn/center-screw arrangement using four M3×12 at ARM-201. Fit the shoulder dowel, two sleeves, 608 bearing, ARM-105 cheek and ARM-109 keeper. Use two 32 mm standoffs/M3×50 stacks and three M2×14 keeper stacks. Mount the shoulder servo to ARM-203 using four M2.5×14 stacks.
7. **Upright to platform:** place the M3 nylocs in ARM-202's underside hex recesses and the small-series washers in the shallow circular seats above them. Bolt ARM-203 down with four M3×14 and top washers. The nut recesses retain orientation and keep all tips above the base backbone. Check the recess fit before final assembly.
8. **Yaw bearing/drive:** fit two 608 bearings in ARM-001. Install the platform spindle and ARM-003 D-drive collar; retain the D interface with the M2×20 crossbolt stack. The spindle/inner-race shoulder must seat without binding. Capture the unmodified SG90 cross horn with ARM-112, four specified low-head M2×10 screws, front washers and nuts; retain the original horn center screw. Fit the SG90 in ARM-004 using two M2×10 stacks, then attach the removable cassette with two M3×30 stacks. Verify cap/gear-cover clearance throughout yaw by hand before power.
9. **Bench and cables:** clamp the 140×120 mm base securely. Route strain-relieved service loops outside every joint sweep; use the existing cable-tie holes. Check screwdriver access and cable clearance in the real assembly. CAD does not model flexible wires.

## Loads, power and proof before repeated use

The solid-PETG/native-volume estimate is **636.9 g** for modeled hardware/prints, excluding supply/controller. With a 20 g payload at 90 mm, cable allowances and a 1.25 load multiplier, elbow design torque is **0.077 N·m**, shoulder **0.241 N·m**. Each uses an assumed **0.277 N·m** operating budget (one-third reference stall torque, further reduced 10%). Margins are **3.60 elbow / 1.15 shoulder**. The gripper's entire specified mass is conservatively allocated at 90 mm because its true mass distribution is unknown. These are sizing assumptions, not measured continuous servo ratings. The shoulder governs; do not increase payload or sustained duty from these numbers alone.

Power servos from the separate regulated supply and appropriately rated distribution, sharing signal ground with the Mega. Keep motor current off the Mega regulator and solderless breadboard rails. Use an accessible DC disconnect and support the arm when power is removed. Verify voltage at the servos during simultaneous starts and choose wiring/protection from measured current and component ratings.

Calibrate one servo at a time with the arm supported, then try slow unloaded motion. The [gripper supplier](https://www.pololu.com/product/3551) specifies an unusually wide nominal pulse range; find actual usable endpoints gradually and stop before hard-stop loading. Feedback indicates position, not grip force. Do not hold a servo stalled to increase grip. Test retention over a catch surface, then increase payload through 5, 10 and 20 g. Record current, voltage, case temperature, drift, slips and fastener movement. If rubber liners are added, retain them mechanically and recalibrate the effective opening.

For the next production-readiness gate, run 50 pick/place cycles with at least 49 successful cycles, record actual placement spread and failures, inspect printed joints/fasteners, and repeat after a sustained-duty trial. Shoulder heating/drift or insufficient repeatability is a reason to reduce load/duty or revise the drive. No cycle, thermal, grip-force or repeatability performance has yet been measured.

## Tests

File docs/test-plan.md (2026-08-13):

# EOAT Automation Cell — Test Plan

**Written:** YYYY-MM-DD
**Tests requirements from:** `requirements.md`

Every performance requirement needs a test that produces a number. A project without this
file is a project that stops at CAD.

## Test setup

**Equipment:**
- Measurement instrument, resolution, and how it is zeroed

**Fixturing:** <how the part and the measurement are held so results are repeatable>

**Sources of measurement error:** <what could make these numbers wrong>

## Tests

### T-01 — <Test name>

| | |
|---|---|
| **Verifies** | P-01 |
| **Method** | <exact procedure, repeatable by someone else> |
| **Sample size** | n = |
| **Pass criterion** | |

**Raw data:** `<datafile>`

**Result:**

**Pass / Fail:**

**Observations:** <anything unexpected — this is often where the real finding is>

---

### T-02 — <Test name>

<repeat>

---

## Results summary

| Test | Requirement | Target | Measured | Pass |
|---|---|---|---|---|
| T-01 | P-01 | | | |

## Failure analysis

For every failure: what happened, root cause, fix, and re-test result. Do not delete failed
runs — they are the strongest interview material and the honest record of the design.

| Run | Failure mode | Root cause | Fix | Re-test result |
|---|---|---|---|---|
| | | | | |

## Conclusions

<What the data actually supports. State it no more strongly than the measurement allows.>

## Log to Engineering OS

Record each validation event with its measured metric and validation status. Status
vocabulary: *proposed → designed → machined → installed → field-tested → validated*. Never
overstate it.

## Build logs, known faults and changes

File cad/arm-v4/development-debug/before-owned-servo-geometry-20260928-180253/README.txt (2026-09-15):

REVISION D — DEVELOPMENT, 2026-09-12

User-authored revision C fillets/chamfers were inspected and preserved before work.
The original cad/arm-v3 directory has not been regenerated or overwritten.

New structural parts:
ARM-201 Upper link: owned MG996R elbow; retains user C upper-link history.
ARM-202 Yaw platform: derived from user C ARM-002; upright removed.
ARM-203 Shoulder upright: derived from user C ARM-002; four-bolt foot added.
ARM-204 Straight modular forearm: common MG996R metal-horn interface.
ARM-205 Removable Pololu 3551 gripper fork.
ARM-206 Two spacers preventing inward clamping of the gripper's plastic ears.

The supplier STEP and dimension drawing are preserved in source-reference.
HW-202 and HW-203 are purchased gripper reference geometry, not printed parts.
The gripper is a $29.95 candidate; supplier backorders were shown on 2026-09-12.
Confirm availability before buying. Two MG996R servos are already owned.

ARM-D_Modular_parallel_gripper_DEVELOPMENT.SLDASM is the intended new assembly.
Check the current HANDOFF and verification reports for the actual build status.
Uncurated STL/STEP files under parts are development exports, not a printing release.
Do not print the entire parts folder: preserved, superseded C parts are also here.

development-debug/USER-C_20260912_original_references.SLDASM is a backup of C
and intentionally still references original C paths. It is not revision D.

Fabrication/assembly checks still required: actual horn seating, bearing/dowel
fits, tool access, cable routing, friction, temperature/current and repeated cycles.
More serviceable CAD does not establish production readiness without those tests.

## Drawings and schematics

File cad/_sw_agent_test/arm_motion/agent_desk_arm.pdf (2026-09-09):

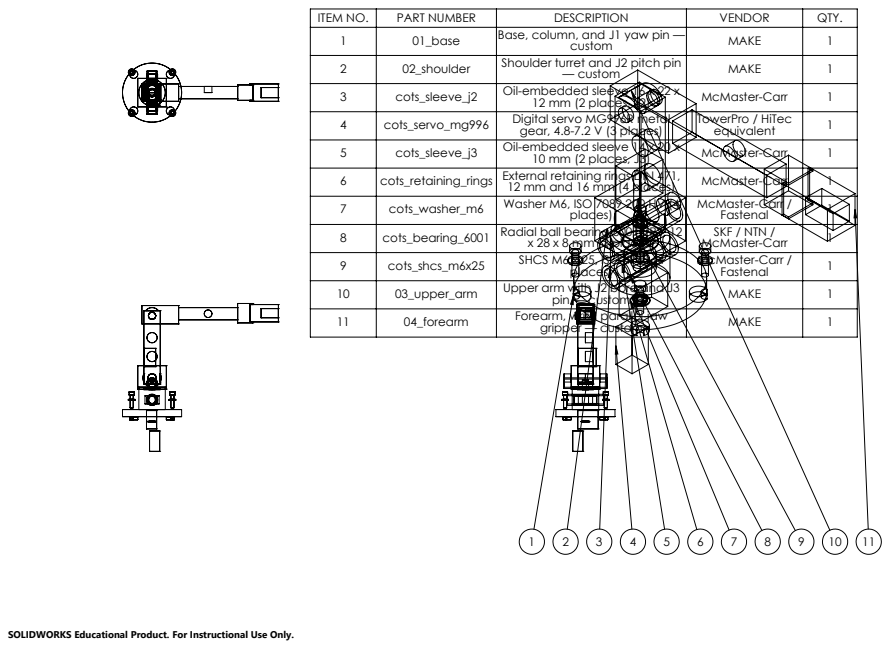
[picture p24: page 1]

ITEM NO. | PART NUMBER | DESCRIPTION | VENDOR | QTY.
1 | 01_base | Base, column, and J1 yaw pin — custom | MAKE | 1
2 | 02_shoulder | Shoulder turret and J2 pitch pin — custom | MAKE | 1
3 | cots_sleeve_j2 | Oil-embedded sleeve 16 x 22 x 12 mm (2 places, J2) | McMaster-Carr | 1
4 | cots_servo_mg996 | Digital servo MG996R metal gear, 4.8-7.2 V (3 places) | TowerPro / HiTec equivalent | 1
5 | cots_sleeve_j3 | Oil-embedded sleeve 14 x 20 x 10 mm (2 places, J3) | McMaster-Carr | 1
6 | cots_retaining_rings | External retaining rings DIN 471, 12 mm and 16 mm (4 places) | McMaster-Carr | 1
7 | cots_washer_m6 | Washer M6, ISO 7089 200 HV (4 places) | McMaster-Carr / Fastenal | 1
8 | cots_bearing_6001 | Radial ball bearing 6001-2RS, 12 x 28 x 8 mm (2 places) | SKF / NTN / McMaster-Carr | 1
9 | cots_shcs_m6x25 | SHCS M6 x 25, ISO 4762 (4 places) | McMaster-Carr / Fastenal | 1
10 | 03_upper_arm | Upper arm with J2 bore and J3 pin — custom | MAKE | 1
11 | 04_forearm | Forearm, wrist, parallel-jaw gripper — custom | MAKE | 1

SOLIDWORKS Educational Product. For Instructional Use Only.

DESK ARM ASSEMBLY

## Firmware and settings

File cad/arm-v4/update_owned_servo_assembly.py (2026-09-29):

"""Replace every nominal servo envelope in the saved D assembly with the owned files.

Edits the existing assembly in place (no rebuild): new owned-servo, hub, centre-screw and
fastener components are inserted at the home pose, a checkpoint is saved before mating,
new lock mates are created while every parent is still at home, then the superseded
nominal components, their mates and the old joint-axis mates are suppressed and renamed.
"""
import json, math, sys
from build_assembly import Assembly, ROOT, connect, call, integer_ref, nothing, pythoncom, win32com, rotation_z, compose, point, I, TOP
import owned_servo_design as D

PATH = ROOT/'ARM-D_Modular_parallel_gripper_DEVELOPMENT.SLDASM'
SUFFIX = '_superseded_nominal_servo'
SINGLE = {'yaw_servo', 'shoulder_servo', 'elbow_servo', 'yaw_horn', 'shoulder_horn', 'elbow_horn', 'yaw_horn_cap'}
PREFIXES = ('yaw_servo_mount_', 'shoulder_servo_mount_', 'elbow_servo_mount_', 'shoulder_horn_', 'elbow_horn_', 'yaw_horn_capture_')
NUT_H = {('nyloc', 3): 4.0, ('hex', 2): 1.6, ('hex', 3): 2.4}

def log(*args): print(*args, flush=True)

def main():
    sw = connect()
    report = json.loads((ROOT/'assembly-build-report.json').read_text())
    if 'owned_servo_update' in report: raise RuntimeError('Owned-servo update already recorded in the build report')
    rows = {r['key']: r for r in report['components']}
    old = sorted(k for k in rows if k in SINGLE or k.startswith(PREFIXES))
    if len(old) != 75: raise RuntimeError(f'Expected 75 superseded nominal components, found {len(old)}')
    old_locks = [m['name'] for m in report['mates'] if m['type'] == 'lock' and m['child'] in old]
    old_mates = old_locks+['J2_shoulder_axis', 'J3_elbow_axis']

    a = Assembly.__new__(Assembly); a.sw = sw; a.models = {}; a.existing = []
    a.doc = sw.OpenDoc6(str(PATH), 2, 1, '', integer_ref(), integer_ref())
    if a.doc is None: raise RuntimeError('Assembly did not open')
    from build_assembly import methods
    methods(a.doc, ['AddComponent5', 'AddMate5', 'ClearSelection2', 'EditRebuild3', 'ForceRebuild3'])
    a.report = report
    if call(call(a.doc, 'GetActiveConfiguration'), 'Name') != '01_Home':
        call(a.doc, 'ShowConfiguration2', '01_Home')
    call(a.doc, 'ForceRebuild3', False)
    cs = {call(c, 'Name2'): c for c in call(a.doc, 'GetComponents', False)}
    a.components = {r['key']: cs[r['instance']] for r in report['components']}

    def residual(keys):
        worst = 0.
        for key in keys:
            r = next(x for x in report['components'] if x['key'] == key)
            want = [r['rotation'][j][i] for i in range(3) for j in range(3)]+[v/1000 for v in r['position_mm']]
            got = list(call(call(a.components[key], 'Transform2'), 'ArrayData'))[:12]
            worst = max(worst, max(abs(x-y) for x, y in zip(want, got)))
        return worst
    home = residual(list(rows))
    log('Home residual before edits', home)
    if home > 1e-6: raise RuntimeError('Assembly is not at the recorded home pose')
    for key in old:
        if a.doc.FeatureByName(rows[key]['instance']) is None: raise RuntimeError('Component feature lookup failed: '+key)
    for name in old_mates:
        if a.doc.FeatureByName(name) is None: raise RuntimeError('Missing superseded mate '+name)

    shoulder = rotation_z(45)
    upper_origin = rows['upper']['position_mm']
    forearm_origin = rows['forearm']['position_mm']
    forearm_rotation = rows['forearm']['rotation']
    new_attachments, stacks = [], []

    def attached(key, filename, parent, pos, rot, hardware):
        a.add(key, filename, pos, rot, hardware)
        new_attachments.append((key, parent))

    def stack(label, parent, origin, rot, xy, top, bottom, d, length, nut_kind, washers, note):
        nut_h = NUT_H[(nut_kind, d)]
        w = .5 if washers else 0.
        items = [('screw', f'HW-S_M{d}x{length}_socket_ENVELOPE', top+w)]
        if washers:
            items += [('head_washer', f'HW-W_M{d}_washer_0p5_ENVELOPE', top), ('nut_washer', f'HW-W_M{d}_washer_0p5_ENVELOPE', bottom-.5)]
        items += [('nut', f'HW-N_M{d}_{nut_kind}_ENVELOPE', bottom-w-nut_h)]
        for suffix, filename, z in items:
            item_rot = compose(rot, rotation_z(30)) if suffix == 'nut' else rot
            attached(label+'_'+suffix, filename, parent, point(rot, (*xy, z), origin), item_rot, True)
        stacks.append({'label': label, 'parent': parent, 'diameter_mm': d, 'length_mm': length, 'nut': nut_kind,
                       'washers': 2 if washers else 0, 'grip_mm': top-bottom,
                       'thread_protrusion_mm': length-(top-bottom+2*w+nut_h), 'note': note})

    prior = sw.CommandInProgress; visible = sw.GetDocumentVisible(1)
    try:
        sw.CommandInProgress = True
        sw.DocumentVisible(False, 1)
        # Owned servos, placed from the measured interface frames.
        mounts = {'shoulder_servo_owned': (D.MG, D.MG_FILE, I, (0, 122, D.MG_PLATE), 'yaw'),
                  'elbow_servo_owned': (D.MG, D.MG_FILE, shoulder, point(shoulder, (60, 0, D.MG_PLATE), upper_origin), 'upper'),
                  'yaw_servo_owned': (D.SG, D.SG_FILE, TOP, (0, D.SG_SHELF_TOP_WORLD_Y, 0), 'base')}
        for key, (servo, filename, rw, origin, parent) in mounts.items():
            rot, pos = D.servo_transform(servo, rw, origin)
            attached(key, filename, parent, pos, rot, False)
        # Printed spline hubs and the servos' own centre screws.
        attached('shoulder_spline_hub', 'ARM-207_MG996R_printed_spline_hub', 'upper', point(shoulder, (0, 0, -D.HUB_THICKNESS), upper_origin), shoulder, False)
        attached('elbow_spline_hub', 'ARM-207_MG996R_printed_spline_hub', 'forearm', point(forearm_rotation, (0, 0, -D.HUB_THICKNESS), forearm_origin), forearm_rotation, False)
        centre = f'HW-S_M3x{D.MG_CENTRE_SCREW}_LOW_HEAD_D5p5_H2_ENVELOPE'
        attached('shoulder_spline_screw', centre, 'upper', point(shoulder, (0, 0, 0), upper_origin), shoulder, True)
        attached('elbow_spline_screw', centre, 'forearm', point(forearm_rotation, (0, 0, 0), forearm_origin), forearm_rotation, True)
        attached('yaw_spline_screw', f'HW-S_M2x{D.SG_CENTRE_SCREW}_PAN_HEAD_D4_H1p6_ENVELOPE', 'yaw', (0, D.COLLAR_FLOOR_TOP_Y, 0), TOP, True)
        for role, parent in (('shoulder', 'upper'), ('elbow', 'forearm')):
            stacks.append({'label': role+'_spline_screw', 'parent': parent, 'diameter_mm': 3, 'length_mm': D.MG_CENTRE_SCREW,
                           'head': 'DIN 7984 low head D5.5 x 2.0 on the ARM-207 floor', 'nut': 'none; MG996R spline M3 thread',
                           'thread_engagement_mm': D.MG_CENTRE_SCREW-D.HUB_FLOOR, 'thread_depth_in_file_mm': D.MG_THREAD_DEPTH,
                           'head_to_dowel_gap_mm': 3.0-D.MG_CENTRE_HEAD})
        stacks.append({'label': 'yaw_spline_screw', 'parent': 'yaw', 'diameter_mm': 2, 'length_mm': D.SG_CENTRE_SCREW,
                       'head': 'pan D4.0 x 1.6 on the ARM-003 floor', 'nut': 'none; SG90 output (file shows a 1.0 mm plain hole)',
                       'engagement_mm': D.SG_CENTRE_SCREW-(D.COLLAR_FLOOR_TOP_Y-D.COLLAR_SPLINE_TOP_Y),
                       'head_to_spindle_gap_mm': D.YAW_SPINDLE_END_Y-D.COLLAR_FLOOR_TOP_Y-D.SG_CENTRE_HEAD})
        # Hub-to-link M3 x 12 with nuts captured, recessed 0.5 mm, in ARM-207.
        for role, parent, origin, rot in (('shoulder', 'upper', upper_origin, shoulder), ('elbow', 'forearm', forearm_origin, forearm_rotation)):
            for i, (x, y) in enumerate(D.HUB_POINTS):
                label = f'{role}_hub_{i}'
                attached(label+'_screw', f'HW-S_M3x{D.HUB_SCREW}_socket_ENVELOPE', parent, point(rot, (x, y, 8.5), origin), rot, True)
                attached(label+'_head_washer', 'HW-W_M3_washer_0p5_ENVELOPE', parent, point(rot, (x, y, 8.0), origin), rot, True)
                nut_z = -D.HUB_THICKNESS+D.HUB_NUT_RECESS
                attached(label+'_nut', 'HW-N_M3_hex_ENVELOPE', parent, point(rot, (x, y, nut_z), origin),
                         compose(rot, rotation_z(math.degrees(math.atan2(y, x))+30)), True)
                stacks.append({'label': label, 'parent': parent, 'diameter_mm': 3, 'length_mm': D.HUB_SCREW,
                               'nut': 'M3 hex captured in ARM-207 pocket, recessed 0.5 mm', 'washers': 1,
                               'grip_mm': 8.5-(nut_z+2.4), 'thread_protrusion_mm': round(8.5-D.HUB_SCREW-nut_z, 6)})
        # MG996R ears: M3 through the measured D4 slotted ears; the far ear is 1.754 mm in the file.
        for role, parent, origin, rot in (('shoulder', 'yaw', (0, 122, D.MG_PLATE), I),
                                          ('elbow', 'upper', point(shoulder, (60, 0, D.MG_PLATE), upper_origin), shoulder)):
            for i, xy in enumerate(D.MG_EAR_HOLES):
                top = D.MG_EAR_NEAR if xy[0] < 0 else D.MG_EAR_FAR
                stack(f'{role}_servo_ear_{i}', parent, origin, rot, xy, top, -D.MG_PLATE, 3, D.MG_EAR_SCREW, 'nyloc', True,
                      'owned MG996R ear '+('output end 2.4 mm' if xy[0] < 0 else 'far end 1.754 mm'))
        # SG90 ears: no washers, because hole centres are 2.4 mm from the case walls.
        for i, xy in enumerate(D.SG_EAR_HOLES):
            stack(f'yaw_servo_ear_{i}', 'base', (0, D.SG_SHELF_TOP_WORLD_Y, 0), TOP, xy, D.SG_EAR, -D.SG_SHELF, 2, D.SG_EAR_SCREW, 'hex', False,
                  'owned SG90 ear; washers omitted because a 5 mm washer would overlap the case wall')
        log('Inserted', len(new_attachments), 'components')
    finally:
        sw.DocumentVisible(visible, 1)
        sw.CommandInProgress = prior

    # Durable checkpoint before any mate is created or suppressed.
    call(a.doc, 'EditRebuild3')
    if not call(a.doc, 'Save3', 1, integer_ref(), integer_ref()): raise RuntimeError('Checkpoint save failed')
    log('Saved pre-mate checkpoint')

    new_keys = [k for k, _ in new_attachments]
    if residual([k for k in rows]) > 1e-6: raise RuntimeError('Parents moved during insertion')
    for key, parent in new_attachments:
        a.rigid('Mount_'+key, parent, key)
    log('Created', len(new_attachments), 'lock mates')
    for name in old_mates:
        f = a.doc.FeatureByName(name)
        if f is None: raise RuntimeError('Missing superseded mate '+name)
        if not call(f, 'SetSuppression2', 0, 2, None): raise RuntimeError('Cannot suppress '+name)
        f.Name = name+SUFFIX
    a.mate('J2_shoulder_axis_owned_servo', 1, a.cylinder('upper', 4), a.cylinder('shoulder_servo_owned', 3.0), 0, 2)
    a.mate('J3_elbow_axis_owned_servo', 1, a.cylinder('forearm', 4), a.cylinder('elbow_servo_owned', 3.0), 0, 2)
    for key in old:
        f = a.doc.FeatureByName(rows[key]['instance'])
        if f is None: raise RuntimeError('Missing component feature '+rows[key]['instance'])
        if not call(f, 'SetSuppression2', 0, 2, None): raise RuntimeError('Cannot suppress component '+key)
    call(a.doc, 'ForceRebuild3', False)

    errors = []
    for m in [x for x in report['mates'] if x['name'] not in old_mates]:
        f = a.doc.FeatureByName(m['name'])
        if f is None: raise RuntimeError('Missing mate '+m['name'])
        if call(f, 'IsSuppressed2', 1, None)[0]: continue
        warning = win32com.client.VARIANT(pythoncom.VT_BYREF | pythoncom.VT_BOOL, False)
        code = call(f, 'GetErrorCode2', warning)
        if code: errors.append((m['name'], code))
    if errors: raise RuntimeError('Mate errors after update: '+str(errors))
    cs = {call(c, 'Name2'): c for c in call(a.doc, 'GetComponents', False)}
    a.components = {r['key']: cs[r['instance']] for r in report['components'] if r['key'] not in old}
    worst = residual([k for k in a.components])
    log('Home residual after update', worst)
    if worst > 1e-6: raise RuntimeError('Home pose changed after mate update: '+str(worst))

    # Record: superseded rows move out of the active lists; nothing is deleted.
    report['superseded_components'] = [rows[k] for k in old]
    report['components'] = [r for r in report['components'] if r['key'] not in old]
    report['superseded_mates'] = [dict(m, name=m['name']+SUFFIX) for m in report['mates'] if m['name'] in old_mates]
    report['mates'] = [m for m in report['mates'] if m['name'] not in old_mates]
    old_labels = {s['label'] for s in report['fastener_stacks'] if s['label'].startswith(PREFIXES)}
    report['superseded_fastener_stacks'] = [s for s in report['fastener_stacks'] if s['label'] in old_labels]
    report['fastener_stacks'] = [s for s in report['fastener_stacks'] if s['label'] not in old_labels]+stacks
    report['rigid_attachments'] = [x for x in report['rigid_attachments'] if x[1] not in old and x[0] not in old]+[list(x) for x in new_attachments]
    report['owned_servo_update'] = {'date': '2026-09-28', 'measurements': 'owned-servo-measurements.json',
        'design': 'owned_servo_design.py', 'inserted_components': len(new_keys), 'superseded_components': len(old),
        'superseded_mates': len(old_mates), 'status': 'Native CAD update; physical fits and performance unproven'}
    report['status'] = 'DEVELOPMENT: owned-servo geometry; physical fit and performance tests remain'
    if not call(a.doc, 'Save3', 1, integer_ref(), integer_ref()): raise RuntimeError('Final save failed')
    (ROOT/'assembly-build-report.json').write_text(json.dumps(report, indent=2))
    log('Saved assembly;', len(report['components']), 'active components,', len(report['mates']), 'active recorded mates')
    for model_path in a.models: sw.CloseDoc(model_path)
    sw.CloseDoc(str(PATH))
    log('Closed assembly and inserted part documents')

if __name__ == '__main__':
    main()

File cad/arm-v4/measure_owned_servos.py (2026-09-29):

"""Measure the owned MG996R and SG90 part files from their native B-rep (read-only).

The user's inserted parts are the authority for every servo interface in revision D.
Each file is opened hidden, measured, and closed without saving. Selection rules are
explicit and checked; raw planar/cylindrical face data are kept in the report.
Results use an interface frame per servo: origin on the output axis in the plane of
the ear underside (the face that seats on the printed mount), +Z along the output,
+X toward the far end of the case.
"""
import json, math
from collections import defaultdict
from build_native import ROOT, connect, call, integer_ref

FILES = {'MG996R': ROOT/'parts'/'MG996R_servo.SLDPRT', 'SG90': ROOT/'parts'/'SERVO_SG90.SLDPRT'}

def dump(sw, path):
    was_open = sw.GetOpenDocumentByName(str(path)) is not None
    visible = sw.GetDocumentVisible(1)
    sw.DocumentVisible(False, 1)
    try:
        doc = sw.OpenDoc6(str(path), 1, 1, '', integer_ref(), integer_ref())
        if doc is None: raise RuntimeError('Cannot open '+str(path))
        features = []
        f = call(doc, 'FirstFeature')
        while f:
            features.append({'name': call(f, 'Name'), 'type': call(f, 'GetTypeName2')})
            f = call(f, 'GetNextFeature')
        bodies = []
        for body in call(doc, 'GetBodies2', 0, False) or []:
            faces = []
            for face in call(body, 'GetFaces') or []:
                s = call(face, 'GetSurface')
                row = {'area_mm2': call(face, 'GetArea')*1e6, 'box_mm': [v*1000 for v in call(face, 'GetBox')]}
                if call(s, 'IsPlane'):
                    p = list(call(s, 'PlaneParams')); row.update(kind='plane', normal=p[:3], point_mm=[v*1000 for v in p[3:6]])
                elif call(s, 'IsCylinder'):
                    p = list(call(s, 'CylinderParams'))
                    row.update(kind='cylinder', origin_mm=[v*1000 for v in p[:3]], axis=p[3:6], radius_mm=p[6]*1000)
                else:
                    row.update(kind='other')
                faces.append(row)
            bodies.append({'name': call(body, 'Name'), 'box_mm': [v*1000 for v in call(body, 'GetBodyBox')], 'faces': faces})
        mp = call(doc.Extension, 'CreateMassProperty')
        units = list(call(doc, 'GetUnits'))
        result = {'file': str(path.relative_to(ROOT)), 'length_unit_code': units[0],
                  'features': features, 'bodies': bodies, 'volume_mm3': call(mp, 'Volume')*1e9,
                  'part_box_mm': [v*1000 for v in call(doc, 'GetPartBox', True)],
                  'material': 'not specified in file (mass properties use SolidWorks default density)'}
        if call(doc, 'GetSaveFlag'): raise RuntimeError('Measurement unexpectedly modified '+str(path))
        return result
    finally:
        if not was_open and sw.GetOpenDocumentByName(str(path)) is not None:
            sw.CloseDoc(str(path))
        sw.DocumentVisible(visible, 1)

def planes(body, axis):
    """Planar faces whose normal is parallel to the given file axis (0=X,1=Y,2=Z)."""
    return [f for f in body['faces'] if f['kind'] == 'plane' and abs(abs(f['normal'][axis])-1) < 1e-6]

def cylinders(body, axis=1):
    return [f for f in body['faces'] if f['kind'] == 'cylinder' and abs(abs(f['axis'][axis])-1) < 1e-6]

def near(a, b, tol=1e-3): return abs(a-b) <= tol

def mg996r(d):
    spline = max(d['bodies'], key=lambda b: b['box_mm'][4])
    case = next(b for b in d['bodies'] if b is not spline)
    lands = [f for f in cylinders(spline) if 2.9 < f['radius_mm'] < 3.0 and f['area_mm2'] < 5]
    teeth = len(lands)
    tip_r = lands[0]['radius_mm']
    ax_x, ax_z = lands[0]['origin_mm'][0], lands[0]['origin_mm'][2]
    top = spline['box_mm'][4]
    y_levels = sorted({round(f['point_mm'][1], 3) for f in planes(spline, 1)})
    teeth_base = y_levels[-2]
    length = top - teeth_base
    land_w = lands[0]['area_mm2']/length
    flanks = [f for f in spline['faces'] if f['kind'] == 'plane' and abs(f['normal'][1]) < 0.5 and f['area_mm2'] > 0.5]
    slant = flanks[0]['area_mm2']/length
    opening = 2*math.pi*tip_r/teeth - land_w
    groove = math.sqrt(slant**2-(opening/2)**2)
    bore = [f for f in cylinders(spline) if f['radius_mm'] < 1.5]
    bore_r = bore[0]['radius_mm']; bore_bottom = min(f['box_mm'][1] for f in bore)
    thread = [f for f in spline['faces'] if f['kind'] == 'other']
    # Case: ear underside is the lowest downward-facing plane outside the case walls.
    walls_top = sorted(f['point_mm'][0] for f in planes(case, 0) if f['area_mm2'] > 100 and f['box_mm'][1] > 20)
    ear_faces = [f for f in planes(case, 1) if f['box_mm'][3] <= walls_top[0]+1e-6 or f['box_mm'][0] >= walls_top[-1]-1e-6]
    ear_bottom = min(f['point_mm'][1] for f in ear_faces)
    near_end = [f['point_mm'][1] for f in ear_faces if f['box_mm'][3] <= walls_top[0]+1e-6]
    far_end = [f['point_mm'][1] for f in ear_faces if f['box_mm'][0] >= walls_top[-1]-1e-6]
    holes = [f for f in cylinders(case) if near(f['radius_mm'], 2.0) and f['box_mm'][1] >= ear_bottom-1e-6 and f['box_mm'][4] <= max(near_end+far_end)+1e-6]
    hole_x = sorted({round(f['origin_mm'][0]-ax_x, 3) for f in holes}); hole_y = sorted({round(-(f['origin_mm'][2]-ax_z), 3) for f in holes})
    xs_all = [f['point_mm'][0] for f in planes(case, 0)]
    zs = [f['point_mm'][2] for f in planes(case, 2) if f['area_mm2'] > 1000]
    bottom_walls = [f['point_mm'][0] for f in planes(case, 0) if f['box_mm'][4] <= 7.0 and f['area_mm2'] > 50]
    tops = defaultdict(list)
    for f in planes(case, 1):
        if f['point_mm'][1] > ear_bottom+3:
            tops[round(f['point_mm'][1]-ear_bottom, 3)].append([round(f['box_mm'][0]-ax_x, 3), round(f['box_mm'][3]-ax_x, 3), round(-f['box_mm'][5]+ax_z, 3), round(-f['box_mm'][2]+ax_z, 3)])
    top_cyl = sorted({(round(f['radius_mm'], 3), round(f['origin_mm'][0]-ax_x, 3), round(f['box_mm'][4]-ear_bottom, 3)) for f in cylinders(case) if f['box_mm'][1] >= ear_bottom+7})
    ring = max((c for c in top_cyl if abs(c[1]) < 1e-3 and c[0] > 4), key=lambda c: c[2])
    m = {'file_frame_to_interface': {'origin_file_mm': [ax_x, ear_bottom, ax_z],
            'interface_X_in_file': [1, 0, 0], 'interface_Y_in_file': [0, 0, -1], 'interface_Z_in_file': [0, 1, 0]},
         'bodies': [b['name'] for b in d['bodies']],
         'output_spline': {'type': 'straight-sided V serration modeled with flat flanks', 'teeth': teeth,
            'tip_diameter_mm': 2*tip_r, 'root_diameter_estimate_mm': 2*(tip_r-groove),
            'tooth_land_mm': land_w, 'groove_depth_mm': groove,
            'top_above_ear_underside_mm': top-ear_bottom, 'teeth_start_above_ear_underside_mm': teeth_base-ear_bottom,
            'exposed_above_output_ring_mm': top-ear_bottom-ring[2]},
         'centre_screw_hole': {'bore_diameter_mm': 2*bore_r, 'depth_from_spline_top_mm': top-bore_bottom,
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

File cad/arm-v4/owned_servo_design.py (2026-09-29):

"""Revision D interfaces derived from the measured owned-servo files.

All lengths are mm in the servo interface frame recorded in owned-servo-measurements.json:
origin on the output axis in the ear-underside plane, +Z along the output, +X toward the
far end of the case. Nothing here comes from the earlier nominal HW-003/HW-004 envelopes,
the assumed OD20/PCD14 metal horn or the assumed 13.2 mm SG90 horn height.
"""
import json
from pathlib import Path

ROOT = Path(__file__).resolve().parent
M = json.loads((ROOT/'owned-servo-measurements.json').read_text())
MG, SG = M['MG996R'], M['SG90']

# ---- MG996R, shoulder and elbow -------------------------------------------------------
MG_FILE = 'MG996R_servo'
MG_EAR_HOLES = [(x, y) for x in MG['ears']['hole_x_from_axis_mm'] for y in MG['ears']['hole_y_mm']]
MG_EAR_NEAR = MG['ears']['thickness_output_end_mm']     # ear on the output end (x < 0)
MG_EAR_FAR = MG['ears']['thickness_far_end_mm']         # modeled thinner far ear (x > 0)
MG_CASE_BOTTOM_X = MG['case']['x_from_axis_at_bottom_mm']  # widest section passes the window
MG_CASE_WIDTH = MG['case']['width_mm']
MG_SPLINE_TOP = MG['output_spline']['top_above_ear_underside_mm']      # 15.5
MG_RING_TOP = MG['output_ring']['top_above_ear_underside_mm']          # 12.0, highest case face
MG_TIP_D = MG['output_spline']['tip_diameter_mm']                      # 5.997
MG_THREAD_DEPTH = MG['centre_screw_hole']['depth_from_spline_top_mm']  # 8.19, M3
WINDOW_CLEARANCE = 0.5
MG_WINDOW = (MG_CASE_BOTTOM_X[0]-WINDOW_CLEARANCE, -(MG_CASE_WIDTH/2+WINDOW_CLEARANCE),
             MG_CASE_BOTTOM_X[1]+WINDOW_CLEARANCE, MG_CASE_WIDTH/2+WINDOW_CLEARANCE)
MG_PLATE = 4.0            # existing upright plate and upper-link servo pad thickness
MG_EAR_SCREW = 14         # M3 x 14 through each slotted D4 ear, two washers, nyloc

# Printed spline hub ARM-207 replaces the unowned metal horn. Its underside clears the
# output ring; its floor seats on the spline top so the links keep their existing Z.
HUB_GAP = 0.5
HUB_FLOOR = 1.0
HUB_THICKNESS = MG_SPLINE_TOP+HUB_FLOOR-(MG_RING_TOP+HUB_GAP)            # 4.0
HUB_UNDERSIDE = MG_RING_TOP+HUB_GAP                                        # 12.5 above ears
LINK_REAR_ABOVE_EARS = HUB_UNDERSIDE+HUB_THICKNESS                         # 16.5
HUB_OD = 28.0
HUB_SOCKET_D = 5.80        # nominal press/broach fit on the 5.997 tip diameter; FIT-003 selects
HUB_SOCKET_DEPTH = MG_SPLINE_TOP-HUB_UNDERSIDE                             # 3.0 engagement
HUB_PCD = 18.0
HUB_POINTS = [(HUB_PCD/2, 0), (0, HUB_PCD/2), (-HUB_PCD/2, 0), (0, -HUB_PCD/2)]
HUB_NUT_AF = 5.7           # M3 hex nut AF5.5 plus clearance
HUB_NUT_RECESS = 0.5
HUB_NUT_POCKET = HUB_NUT_RECESS+2.4
HUB_SCREW = 12             # M3 x 12 from the link face; tip meets the recessed nut underside
MG_CENTRE_SCREW = 8        # M3 x 8 low head (DIN 7984, D5.5 x 2.0) into the spline thread
MG_CENTRE_HEAD = 2.0

# ---- SG90, yaw -------------------------------------------------------------------------
SG_FILE = 'SERVO_SG90'
SG_EAR_HOLES = [(x, 0.0) for x in SG['ears']['hole_x_from_axis_mm']]
SG_EAR = SG['ears']['thickness_mm']
SG_COVER_TOP = SG['gear_cover']['top_above_ear_underside_mm']          # 11.4
SG_SPLINE_TOP = SG['output_spline']['top_above_ear_underside_mm']      # 14.4
SG_SPLINE_D = SG['output_spline']['diameter_mm']
SG_SHELF_TOP_WORLD_Y = 25.4   # existing ARM-004 shelf top; the ear underside seats here
SG_SHELF = 4.0
SG_EAR_SCREW = 10             # M2 x 10, no washers: hole centres are 2.4 mm from the case walls
COLLAR_GAP = 0.5
COLLAR_SOCKET_BOTTOM_Y = SG_SHELF_TOP_WORLD_Y+SG_COVER_TOP+COLLAR_GAP   # 37.3
COLLAR_SPLINE_TOP_Y = SG_SHELF_TOP_WORLD_Y+SG_SPLINE_TOP                # 39.8
COLLAR_FLOOR_TOP_Y = 41.0     # existing collar flange underside
COLLAR_SOCKET_D = 4.85        # nominal press fit on the modeled 5.0 spline; FIT-004 selects
COLLAR_BOSS_OD = 12.0
SG_CENTRE_SCREW = 4           # M2 x 4 pan head (D4.0 x 1.6), the servo's own horn screw class
SG_CENTRE_HEAD = 1.6
YAW_SPINDLE_END_Y = 43.0      # existing ARM-202 spindle end, must clear the screw head

# ---- transforms ------------------------------------------------------------------------
def file_rotation(servo):
    f = servo['file_frame_to_interface']
    return [f['interface_X_in_file'], f['interface_Y_in_file'], f['interface_Z_in_file']]

def matmul(a, b):
    return [[sum(a[i][k]*b[k][j] for k in range(3)) for j in range(3)] for i in range(3)]

def servo_transform(servo, mount_rotation, mount_origin):
    """Component rotation (columns are file axes in world) and translation for a servo
    whose interface frame is placed at mount_origin with mount_rotation."""
    rot = matmul(mount_rotation, file_rotation(servo))
    f0 = servo['file_frame_to_interface']['origin_file_mm']
    pos = [mount_origin[i]-sum(rot[i][j]*f0[j] for j in range(3)) for i in range(3)]
    return rot, pos

def checks():
    assert abs(HUB_THICKNESS-4.0) < 1e-9 and abs(LINK_REAR_ABOVE_EARS-16.5) < 1e-9
    assert abs(HUB_SOCKET_DEPTH-3.0) < 1e-9
    assert abs(COLLAR_SPLINE_TOP_Y-39.8) < 1e-9 and abs(COLLAR_SOCKET_BOTTOM_Y-37.3) < 1e-9
    assert COLLAR_FLOOR_TOP_Y+SG_CENTRE_HEAD <= YAW_SPINDLE_END_Y-0.3
    # Screw engagement and tip positions (ear-underside frame).
    assert MG_SPLINE_TOP+HUB_FLOOR-MG_CENTRE_SCREW > MG_SPLINE_TOP-MG_THREAD_DEPTH
    return True

checks()

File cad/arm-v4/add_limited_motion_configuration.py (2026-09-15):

"""Add a separate native drag configuration with provisional joint angle limits."""
import json,math,shutil
from datetime import datetime
from build_native import ROOT,connect,call,integer_ref,pythoncom,win32com
sw=connect(); path=ROOT/'ARM-D_Modular_parallel_gripper_DEVELOPMENT.SLDASM'
backup=ROOT/'development-debug'/('before-limited-motion-'+datetime.now().strftime('%Y%m%d-%H%M%S'))
backup.mkdir(parents=True); shutil.copy2(path,backup/path.name)
doc=sw.OpenDoc6(str(path),2,1,'',integer_ref(),integer_ref())
cm=call(doc,'ConfigurationManager'); name='07_Free_motion_CHECK_COLLISIONS'
if doc.GetConfigurationByName(name) is None:
 call(cm,'AddConfiguration2',name,'Provisional angular bounds; arbitrary combinations and physical servo limits are unverified','',0,'','Free articulation with limit mates',True)
call(doc,'ShowConfiguration2',name)
commands=[('J1_Yaw_command',30,150),('J2_Shoulder_command',75,170),
          ('J3_Elbow_command',5,100)]
build=json.loads((ROOT/'assembly-build-report.json').read_text())
instances={r['key']:r['instance'] for r in build['components']}
components={call(c,'Name2'):c for c in call(doc,'GetComponents',False)}
refs={'J1_Yaw_command':('base','Top Plane'),'J2_Shoulder_command':('yaw','Front Plane'),
      'J3_Elbow_command':('upper','Front Plane')}
rows=[]
try:
 for command,low,high in commands:
  f=doc.FeatureByName(command)
  if not call(f,'SetSuppression2',0,1,None): raise RuntimeError('Could not release '+command)
 for command,low,high in commands:
  limit_name=command.replace('_command','_travel_limit')
  f=doc.FeatureByName(limit_name)
  if f is None:
   definition=call(doc.FeatureByName(command),'GetDefinition')
   data=call(doc,'CreateMateData',6)
   data.EntitiesToMate=win32com.client.VARIANT(pythoncom.VT_ARRAY|pythoncom.VT_DISPATCH,call(definition,'EntitiesToMate'))
   key,plane=refs[command]; c=components[instances[key]]
   ref=c.GetCorresponding(call(c,'GetModelDoc2').FeatureByName(plane))
   call(doc,'ClearSelection2',True)
   if not ref.Select2(False,67108864): raise RuntimeError('Direction reference selection failed')
   data.ReferenceEntity=call(doc.SelectionManager,'GetSelectedObject6',1,67108864)
   data.MateAlignment=call(definition,'MateAlignment')
   data.IsAdvancedMate=True; data.Angle=call(definition,'Angle')
   data.MinimumAngle=math.radians(low); data.MaximumAngle=math.radians(high)
   f=call(doc,'CreateMate',data)
   if f is None: raise RuntimeError('Could not create '+limit_name)
   f.Name=limit_name
  if not call(f,'SetSuppression2',0,2,None): raise RuntimeError('Could not isolate '+limit_name)
  if not call(f,'SetSuppression2',1,1,None): raise RuntimeError('Could not enable '+limit_name)
  actual=call(f,'GetDefinition')
  row={'name':limit_name,'minimum_mate_angle_deg':math.degrees(call(actual,'MinimumAngle')),
       'maximum_mate_angle_deg':math.degrees(call(actual,'MaximumAngle'))}
  rows.append(row); print('Created',row,flush=True)
 call(doc,'EditRebuild3')
 for row in rows:
  warning=win32com.client.VARIANT(pythoncom.VT_BYREF|pythoncom.VT_BOOL,False)
  err=call(doc.FeatureByName(row['name']),'GetErrorCode2',warning)
  if err: raise RuntimeError('Limit mate error '+str(err))
 (ROOT/'native-motion-limits.json').write_text(json.dumps({'configuration':name,
  'status':'Native bounds verified; not a certification of all combined poses or actual servo travel','limits':rows},indent=2))
finally:
 call(doc,'ShowConfiguration2','01_Home'); call(doc,'EditRebuild3')
 if not call(doc,'Save3',1,integer_ref(),integer_ref()): raise RuntimeError('Could not save assembly')

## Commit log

2026-06-12 Project Proposal
    End of arm tool file structure and project definition
2026-06-12 Create bom.md
    electrical/hardware component bill of material setup
2026-09-09 Added EOAT automation cad updates
    [01_base.SLDPRT, 02_shoulder.SLDPRT, 03_upper_arm.SLDPRT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]
2026-09-15 Rev 4- EOAT
    project updates, rev 4, cad model, BOM, etc
    [ARM-001_Base_pedestal.SLDPRT, ARM-001_Base_pedestal.STL, ARM-001_Base_pedestal.step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]
2026-09-23 Adding parts
    [ARM-203_Bolted_shoulder_upright.SLDPRT, ARM-C_Articulated_prototype_DEVELOPMENT.SLDASM, ARM-D_Modular_parallel_gripper_DEVELOPMENT.SLDASM]
2026-09-29 CAD changes
    [ARM-003_Yaw_D_drive_collar.SLDPRT, ARM-003_Yaw_D_drive_collar.STL, ARM-003_Yaw_D_drive_collar.step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]
